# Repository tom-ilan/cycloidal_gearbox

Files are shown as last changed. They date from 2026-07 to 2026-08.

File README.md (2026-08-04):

# Cycloidal Gearbox ⚙️

This is my cycloidal gearbox I built, and the python script I created to generate it! A cycloidal gearbox is a type of gearbox that allows you to turn rotational speed into torque. 

Gearbox Demo

## Design Process

### Version 1

This gearbox was a handcranked gearbox specifically meant to test the validity of the python cycloidal generator. It had a gear ratio of 1:9. 

### Version 2

This design was a micro cycloidal gearbox with a ratio of 1:9, meant to only take up the same footprint as a NEMA 17. Due to the tight tolerances needed for a small cycloidal drive and the lack of precision offered by 3D printing, this design did not work.

### Version 3

This gearbox was the first working version to run on a NEMA 17. It has a larger footprint compared to Version 2 allowing greater tolerances and a fully functional design.

---

## 🛠️ The Python Script

This python script was based on the SolidWorks article *Building a Cycloidal Drive with SOLIDWORKS*. The two main parametric equations I used were: 

$$x = R \cos(t) - E \cos(N t) - r \cos(t + \psi), \quad y = R \sin(t) - E \sin(N t) - r \sin(t + \psi)$$
$$\psi = \text{atan2}\left(\sin((1 - N) t), \frac{R}{E \cdot N} - \cos((1 - N) t)\right)$$
Reduction ratio: **$1 : (N - 1)$** (rotor rotates opposite to input shaft).

### Installation & Execution
1. Clone the repo
2. Open Fusion 360 and launch **Scripts and Add-Ins** (`Shift + S`).
3. Under the **Scripts** tab, click **`+` (Plus)** to add a script.
4. Select the `cycloidal_generator` folder and click **Run**.

### Key Parameters
- **Pins ($N$) & Pitch Radius ($R$):** Sets outer stationary housing geometry (Rotor has $N-1$ lobes).
- **Eccentricity ($E$):** Input shaft offset distance. *(Constraint: $R > E \cdot N$)*.
- **Outer Pin Radius ($r$):** Roller pin radius. *(Constraint: validated against undercut limit $r_{\text{max}}$)*.
- **Precision / Profile Offset:** Angular step size and tolerance offset ($+$ for 3D print clearance).
- **Output Pins & Bolt Radius:** Defines concentric output pins and rotor clearance holes ($r_{\text{pin}} + E$).

---

## 🚀 Version 3 — Detailed Overview & Stats

> [!NOTE]  
> This section is dedicated to **Version 3**, whose CAD files can be found under `cad_models/version_3`.

<p align="center">
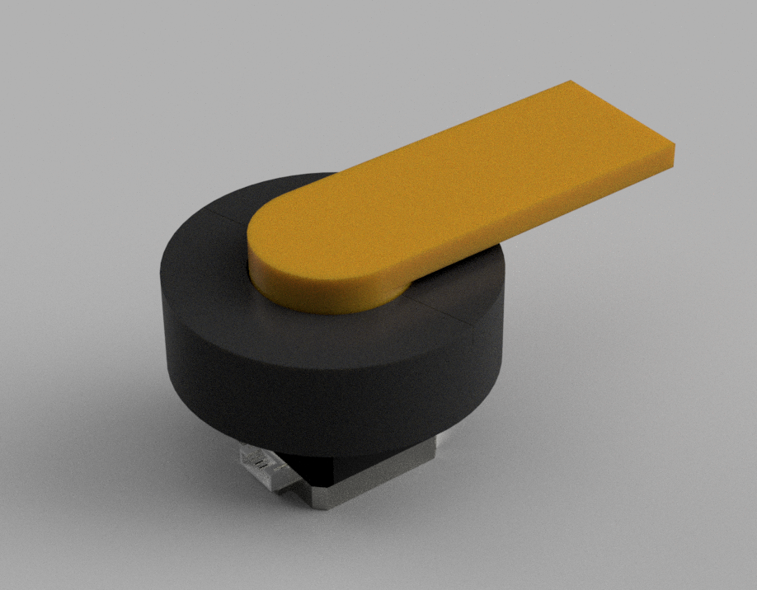
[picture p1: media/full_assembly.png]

</p>

### Key Specifications & Performance Stats

| Metric / Parameter | Value / Detail |
|---|---|
| **Gear Ratio** | 1:9 ($N=10$ outer pins, 9 rotor lobes) |
| **Outer Diameter** | 9.0 cm (90 mm) |
| **Drive Motor** | NEMA 17 Stepper Motor (42bygh40-A24dh)|
| **3D Printing Material** | PLA |
| **Primary Fasteners / Hardware** | 4× **M3 × 8 screws**, 2× **6704 Bearings** |
| **Tolerance Offset Applied** | +0.15 mm (+0.015 cm) all around|
| **Gearbox Torque** | 1.3 N·m ± 0.007 N·m |
| **Base NEMA 17 Torque** | 0.21 N·m ± 0.007 N·m |
| **Efficiency** | 66% ± 0.22% |

#### Further room for growth
1) The housing pins can be replaced with MR128 bearings allowing for less friction and higher efficiency in the gearbox.

2) The output pins can be replaced with M2 screws with metal coverings to increase rigidity, maximum torque output, and the efficiency of the gearbox.

#### Print Settings

The standard bambu labs settings with PLA for a P1S other than:

minimum support x y: 1mm

support interference material: Bambu labs support PLA

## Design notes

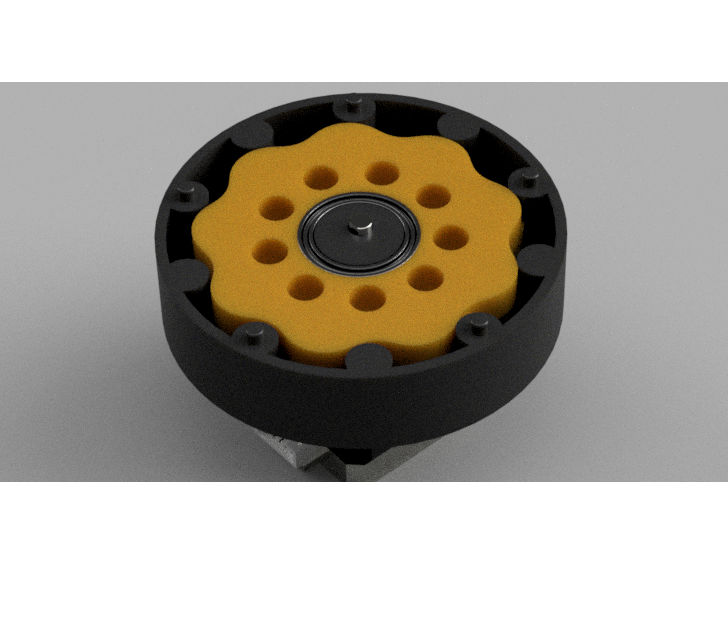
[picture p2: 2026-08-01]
media/topless_drive.png

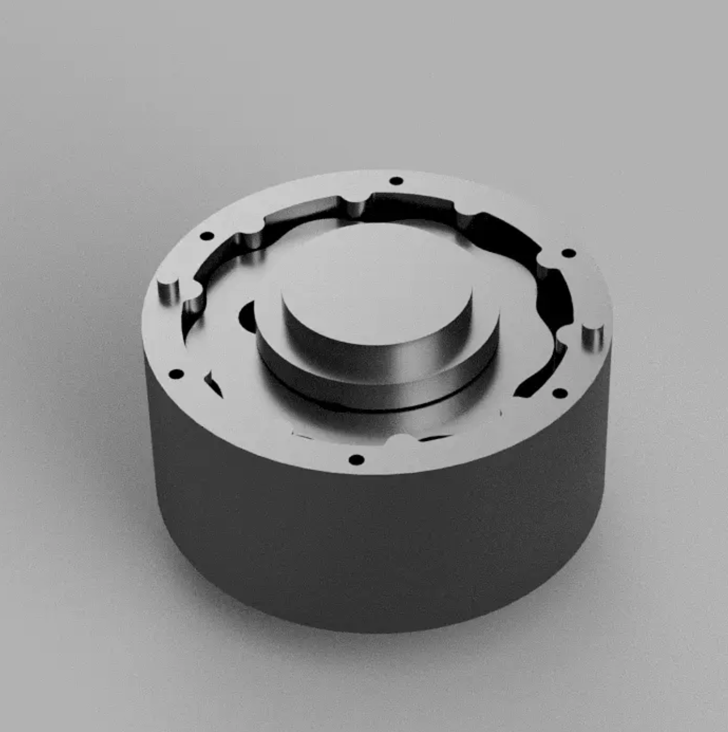
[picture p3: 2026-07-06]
media/Cycloidal_gearbox_1.png

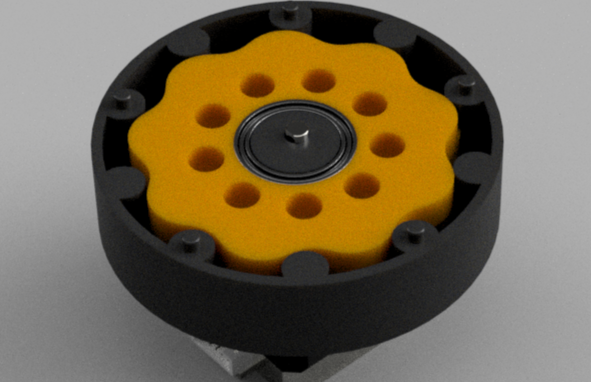
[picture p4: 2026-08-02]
media/topless_2.png

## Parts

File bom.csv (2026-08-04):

Item | Amount
6704 Bearings | 2
PLA | ~500g
A4988 Stepper Driver | 1
Nema 17 Stepper | 1
M3 x 8 screw | 4

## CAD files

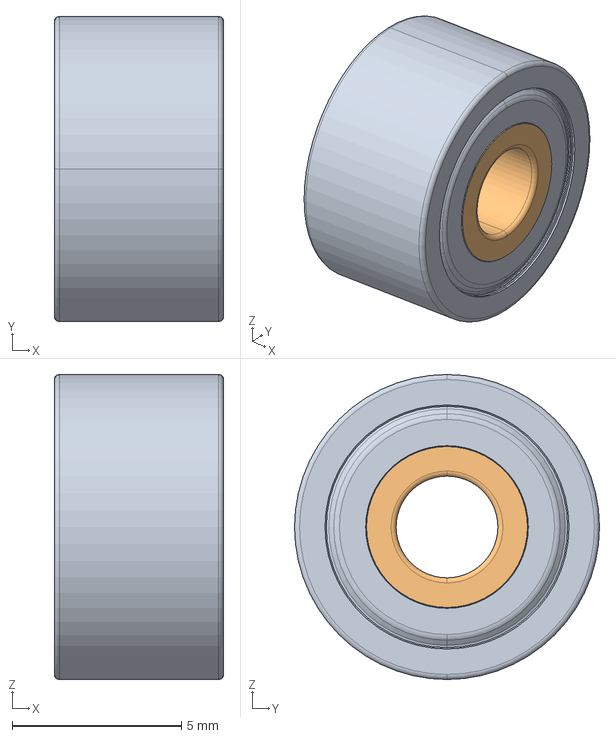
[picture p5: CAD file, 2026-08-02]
cad_models/dependencies/Micro_Steel_Deep_Groove_Ball_Bearings_3D_Model/603zz-EA007/603zz-EA007.stp
5.00 x 9.00 x 9.00 mm

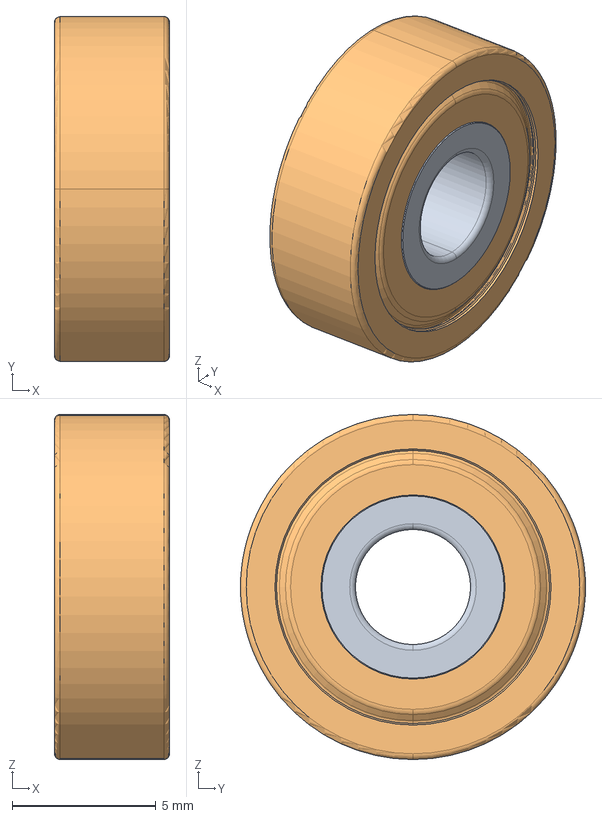
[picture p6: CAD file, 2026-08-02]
cad_models/dependencies/Micro_Steel_Deep_Groove_Ball_Bearings_3D_Model/604zz-EA011/604zz-EA011.stp
4.00 x 12.0 x 12.0 mm

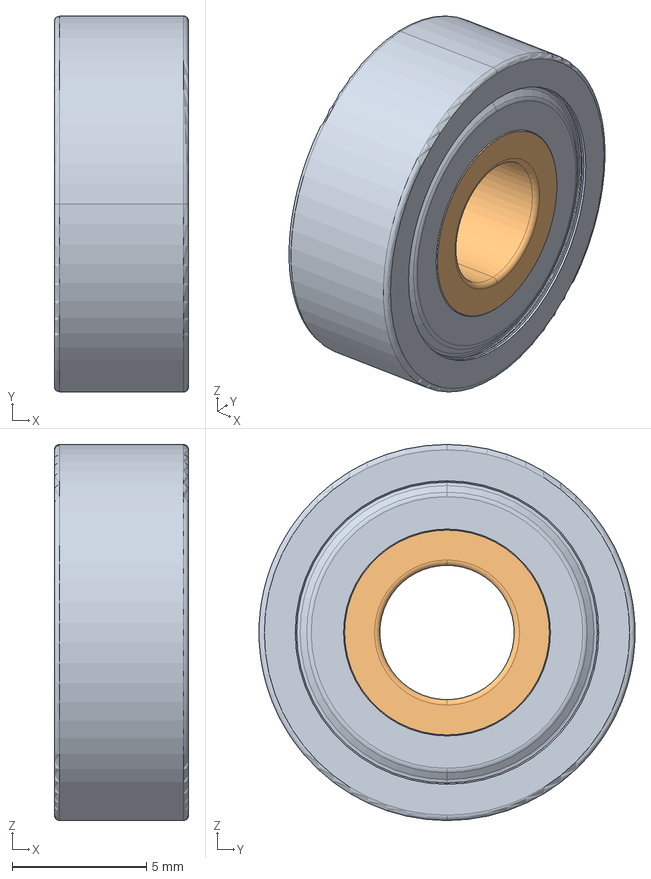
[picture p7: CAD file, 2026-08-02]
cad_models/dependencies/Micro_Steel_Deep_Groove_Ball_Bearings_3D_Model/605zz-EA015/605zz-EA015.stp
5.00 x 14.0 x 14.0 mm

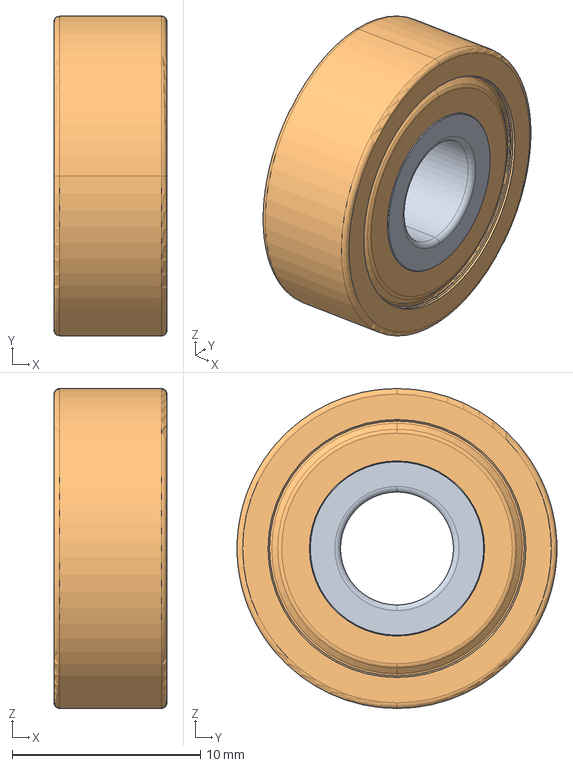
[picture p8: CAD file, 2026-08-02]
cad_models/dependencies/Micro_Steel_Deep_Groove_Ball_Bearings_3D_Model/606zz-EA019/606zz-EA019.stp
6.00 x 17.0 x 17.0 mm

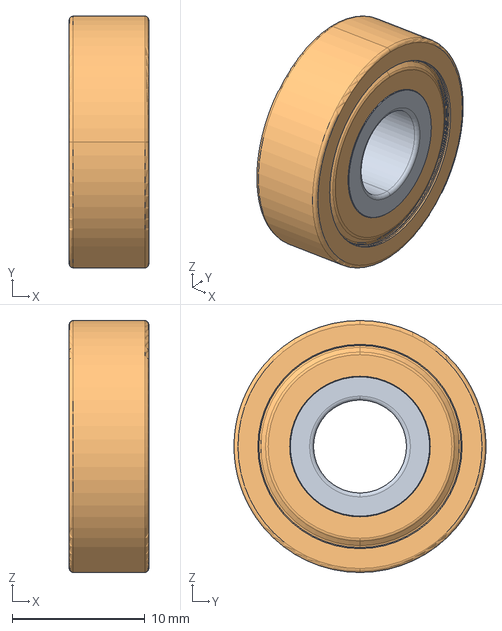
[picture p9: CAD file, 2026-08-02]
cad_models/dependencies/Micro_Steel_Deep_Groove_Ball_Bearings_3D_Model/607zz-EA024/607zz-EA024.stp
6.00 x 19.0 x 19.0 mm

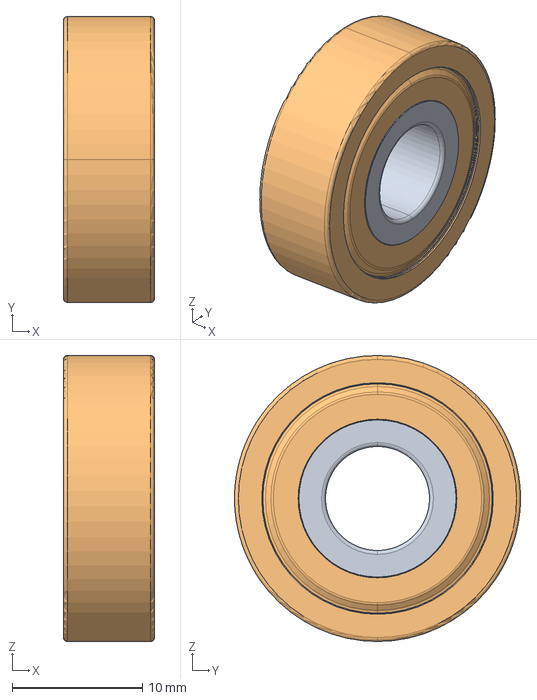
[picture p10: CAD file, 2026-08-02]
cad_models/dependencies/Micro_Steel_Deep_Groove_Ball_Bearings_3D_Model/608-EA027 EA028 EA029/608-EA027 EA028 EA029.stp
7.00 x 22.0 x 22.0 mm

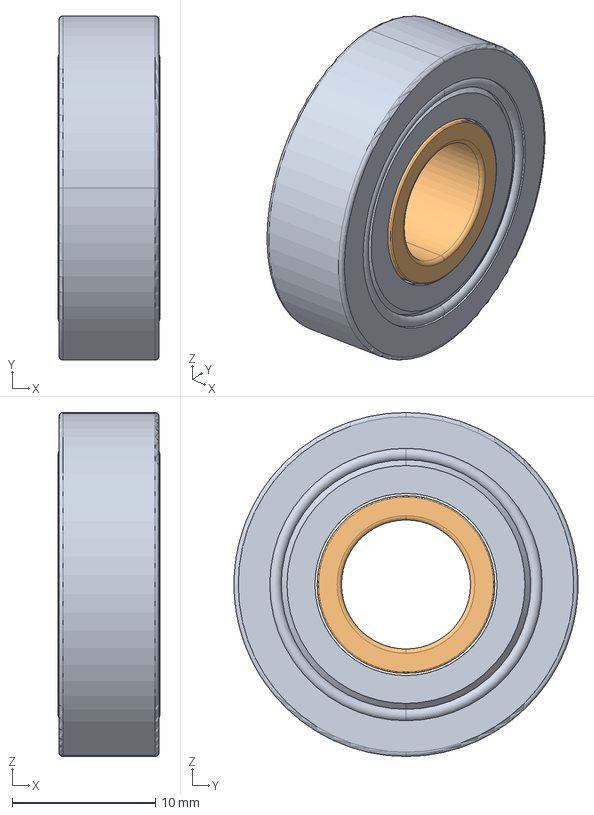
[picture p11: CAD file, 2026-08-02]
cad_models/dependencies/Micro_Steel_Deep_Groove_Ball_Bearings_3D_Model/609ZZ-EA031/609ZZ-EA031.stp
7.10 x 24.0 x 24.0 mm

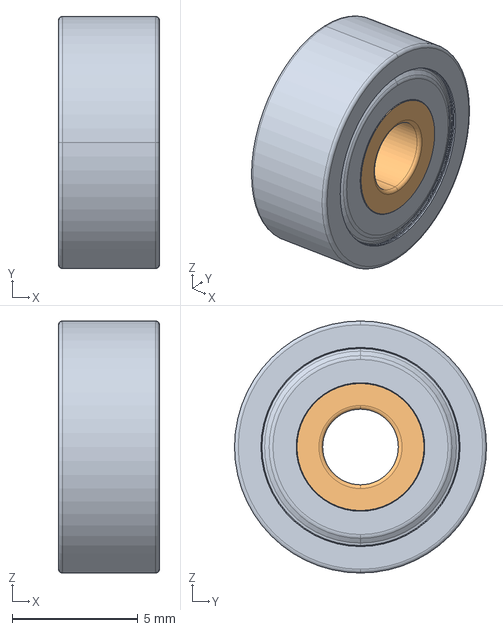
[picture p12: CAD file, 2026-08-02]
cad_models/dependencies/Micro_Steel_Deep_Groove_Ball_Bearings_3D_Model/623zz-EA008/623zz-EA008.stp
4.00 x 10.0 x 10.0 mm

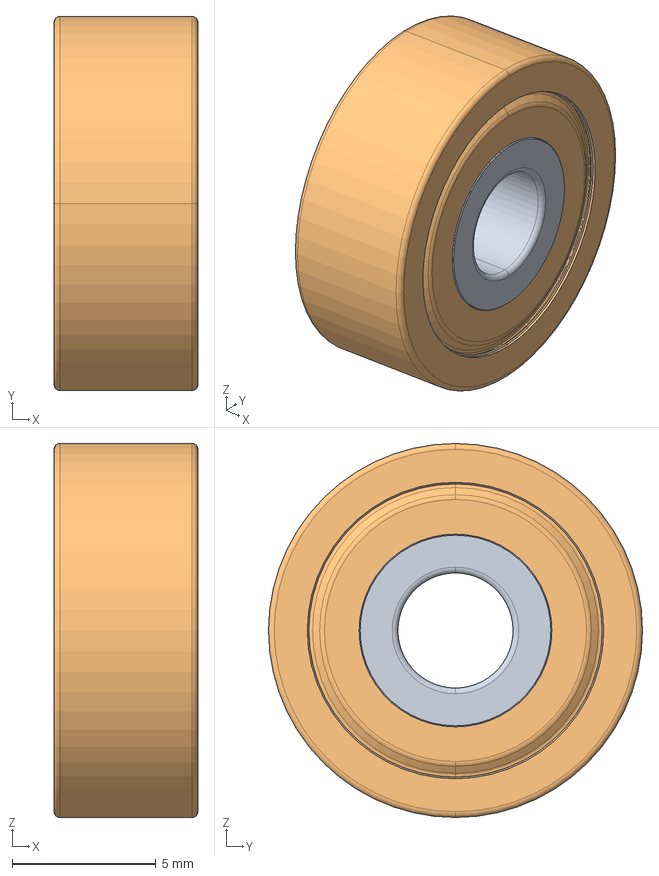
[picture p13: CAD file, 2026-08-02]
cad_models/dependencies/Micro_Steel_Deep_Groove_Ball_Bearings_3D_Model/624zz-EA012/624zz-EA012.stp
5.00 x 13.0 x 13.0 mm

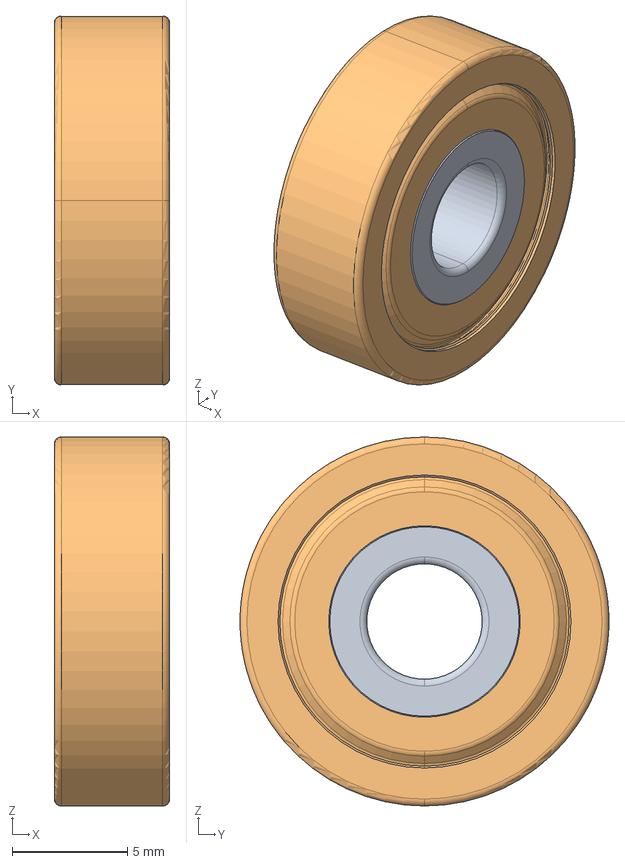
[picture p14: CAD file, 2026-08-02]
cad_models/dependencies/Micro_Steel_Deep_Groove_Ball_Bearings_3D_Model/625zz-EA016/625zz-EA016.stp
5.00 x 16.0 x 16.0 mm

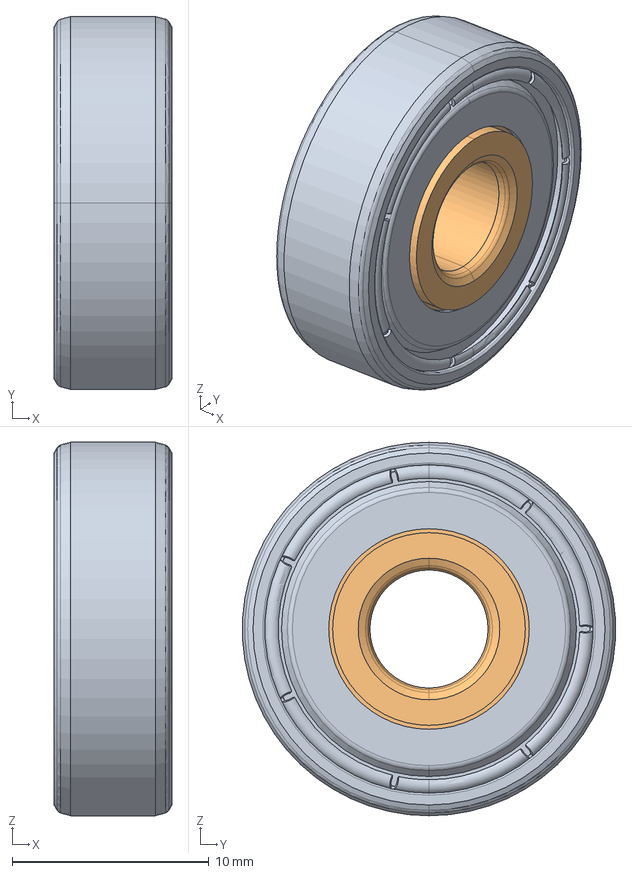
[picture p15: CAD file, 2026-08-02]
cad_models/dependencies/Micro_Steel_Deep_Groove_Ball_Bearings_3D_Model/626ZZ-EA020/626ZZ-EA020.stp
6.00 x 19.0 x 19.0 mm

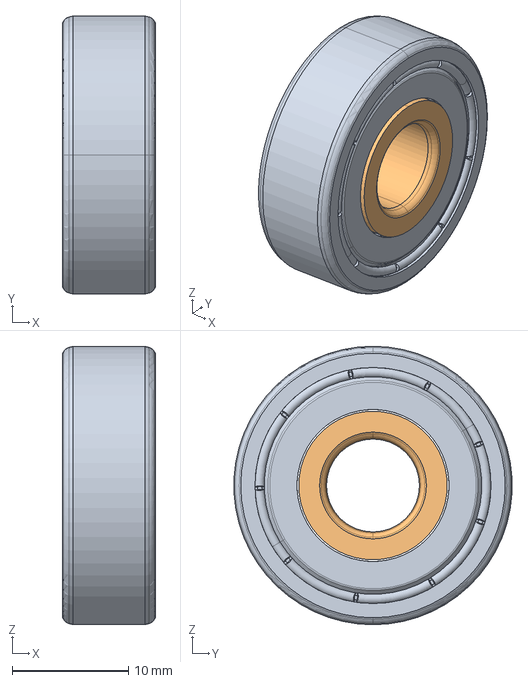
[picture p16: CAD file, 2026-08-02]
cad_models/dependencies/Micro_Steel_Deep_Groove_Ball_Bearings_3D_Model/628ZZ-EA030/628ZZ-EA030.stp
8.00 x 24.0 x 24.0 mm

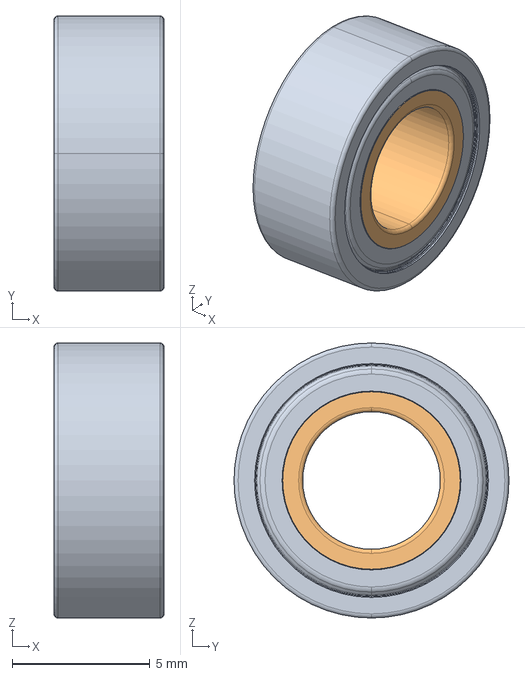
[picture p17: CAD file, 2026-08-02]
cad_models/dependencies/Micro_Steel_Deep_Groove_Ball_Bearings_3D_Model/MR105zz-EA014/MR105zz-EA014.stp
4.00 x 10.0 x 10.0 mm

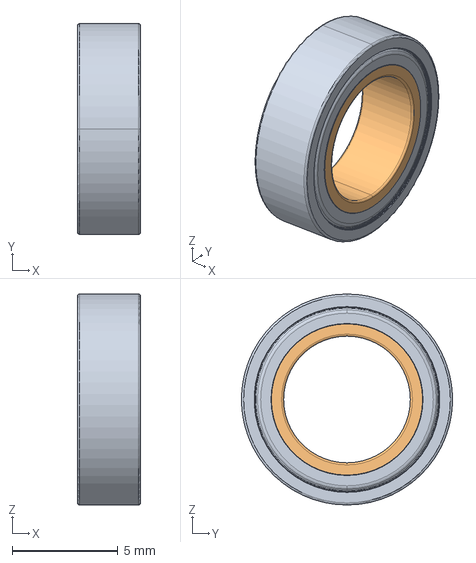
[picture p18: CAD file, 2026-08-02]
cad_models/dependencies/Micro_Steel_Deep_Groove_Ball_Bearings_3D_Model/MR106-EA017/MR106-EA017.stp
3.00 x 10.00 x 10.0 mm

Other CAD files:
cad_models/dependencies/Micro_Steel_Deep_Groove_Ball_Bearings_3D_Model/627zz-EA025/627zz-EA025.stp
cad_models/dependencies/Micro_Steel_Deep_Groove_Ball_Bearings_3D_Model/687zz-EA023/687zz-EA023.stp
cad_models/dependencies/Micro_Steel_Deep_Groove_Ball_Bearings_3D_Model/688zz-EA026/688zz-EA026.stp
cad_models/dependencies/Micro_Steel_Deep_Groove_Ball_Bearings_3D_Model/MR126-EA018/MR126-EA018.stp
cad_models/dependencies/Micro_Steel_Deep_Groove_Ball_Bearings_3D_Model/603zz-EA007/603zz-EA007.stl
cad_models/dependencies/Micro_Steel_Deep_Groove_Ball_Bearings_3D_Model/604zz-EA011/604zz-EA011.stl
cad_models/dependencies/Micro_Steel_Deep_Groove_Ball_Bearings_3D_Model/605zz-EA015/605zz-EA015.stl
cad_models/dependencies/Micro_Steel_Deep_Groove_Ball_Bearings_3D_Model/606zz-EA019/606zz-EA019.stl
cad_models/dependencies/Micro_Steel_Deep_Groove_Ball_Bearings_3D_Model/607zz-EA024/607zz-EA024.stl
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

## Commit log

2026-06-25 added output shafts
2026-07-04 v1_1 and _2 of the drive
    [disk_bottom_v1_1.stl, disk_top_v1_1.stl, disk_v1_2.stl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]
2026-07-06 v1.1 and 1.2. Added proper housing, drive should work now
    [disk_bottom_v1_1.stl, disk_top_v1_1.stl, disk_v1_2_1.stl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]
2026-07-06 tighter tollerences
    [Input_v1_3_1.stl, disk_bottom_v1_3_1.stl, disk_top_v1_3_1.stl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]
2026-07-29 version 3
    [Input_v1_3_1.stl, Input_v3_1_1.stl, Input_v3_1_2.stl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]
2026-07-29 cleaned up files
    [Input_v3_1_1.stl, Input_v3_1_2.stl, disk_v2_1_1.3mf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]
2026-07-31 file cleaning and readme
    [Input_v1_3_1.stl, Input_v3_1_1.stl, Input_v3_1_2.stl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]
2026-07-31 fixed bearing
2026-08-01 fixed up the file orginization
    [disk_v3_3_1_1.stl, disk_v3_3_1_2.stl, disk_v3_3_2_1.stl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]
2026-08-01 fixed torque to acount for the force vector, due to the test arm hitting at an angle
2026-08-02 changed up readme
    [nema_17_test_pole.stl, test_stand.stl, test_stand_v2.stl]
2026-08-02 added the bearing cad files
    [6000ZZ - EA033.stl, 6000ZZ - EA033.stp, 6001ZZ - EA035.stp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]
2026-08-02 added gearbox definition
2026-08-03 added bom
    [bom.csv]
2026-08-04 added print settings
2026-08-04 changed bom
    [bom.csv]
